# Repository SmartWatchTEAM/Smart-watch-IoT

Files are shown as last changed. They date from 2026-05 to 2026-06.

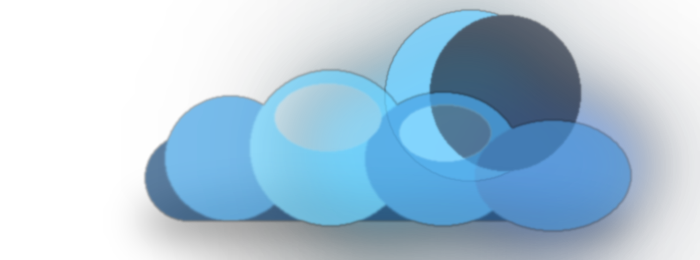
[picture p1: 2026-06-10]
Health_Tracking_Website/assets/images/cloud_weather_transparent.png

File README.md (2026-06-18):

# IoT-based Medical Alert System for Elderly People

## 1. Giới thiệu dự án

**IoT-based Medical Alert System for Elderly People** là đồ án xây dựng mô hình **đồng hồ giám sát sức khỏe thông minh cho người cao tuổi**. Hệ thống sử dụng **ESP32-S3 Super Mini** làm bộ xử lý trung tâm, kết hợp với cảm biến **MAX30102**, cảm biến chuyển động **MPU6500**, màn hình **TFT ST7789**, nút SOS, buzzer và nền tảng **Firebase Realtime Database** để theo dõi dữ liệu sức khỏe theo thời gian thực.

Thiết bị được thiết kế theo hướng nhỏ gọn, có thể hiển thị trực tiếp thông tin trên màn hình TFT và đồng thời gửi dữ liệu lên web dashboard để người thân theo dõi từ xa. Khi phát hiện tình huống bất thường như té ngã hoặc người dùng nhấn giữ nút SOS, hệ thống sẽ kích hoạt cảnh báo tại thiết bị và cập nhật trạng thái lên Firebase để hỗ trợ gửi thông báo cảnh báo.

> **Lưu ý:** Đây là mô hình phục vụ học tập, nghiên cứu và minh họa ứng dụng IoT trong chăm sóc sức khỏe. Kết quả đo BPM và SpO2 chỉ mang tính tham khảo, không thay thế thiết bị y tế chuyên dụng.

---

## 2. Thông tin

### Thành viên thực hiện

| Họ và tên | MSSV |
|---|---|
| Trần Hải Đạt | 24110197 |
| Nguyễn Lê Huy | 24110221 |
| Ninh Nguyễn Minh Tuyên | 24110372 |

---

## 3. Mục tiêu hệ thống

Mục tiêu của đề tài là xây dựng một mô hình đồng hồ sức khỏe IoT có khả năng hỗ trợ theo dõi một số thông số cơ bản của người cao tuổi và cảnh báo khi có tình huống nguy hiểm.

Các mục tiêu chính:

1. Đo nhịp tim BPM bằng cảm biến MAX30102.
2. Đo nồng độ oxy trong máu SpO2 bằng cảm biến MAX30102.
3. Đếm số bước chân bằng dữ liệu chuyển động từ MPU6500.
4. Phát hiện té ngã dựa trên gia tốc, góc nghiêng và trạng thái bất động.
5. Hiển thị thời gian, thời tiết, Wi-Fi, pin, BPM, SpO2 và số bước chân trên màn hình TFT ST7789.
6. Kích hoạt cảnh báo khi phát hiện té ngã hoặc khi người dùng nhấn giữ nút SOS.
7. Gửi dữ liệu sức khỏe và trạng thái cảnh báo lên Firebase Realtime Database.
8. Hiển thị dữ liệu realtime, lịch sử đo và thống kê trên web dashboard.
9. Hỗ trợ xuất báo cáo thống kê sức khỏe ra file PDF.

---

## 4. Chức năng chính

### 4.1. Đo nhịp tim và SpO2

Cảm biến **MAX30102** đọc tín hiệu ánh sáng đỏ và hồng ngoại từ người dùng. Sau khi thu thập đủ mẫu, chương trình xử lý tín hiệu để tính toán:

- Nhịp tim theo đơn vị **BPM**.
- Nồng độ oxy trong máu **SpO2**.
- Trạng thái đặt tay lên cảm biến.
- Chất lượng tín hiệu đo.

Khi tín hiệu chưa ổn định hoặc chưa đặt tay đúng vị trí, giao diện sẽ hiển thị giá trị dạng `--` để tránh hiển thị sai.

### 4.2. Đếm số bước chân

Cảm biến **MPU6500** cung cấp dữ liệu gia tốc theo ba trục. Chương trình phân tích dao động gia tốc để xác định bước đi, từ đó cập nhật:

- Tổng số bước trong ngày.
- Mục tiêu bước chân.
- Phần trăm hoàn thành mục tiêu.
- Quãng đường ước tính.
- Lượng calo ước tính.

### 4.3. Phát hiện té ngã

Hệ thống sử dụng MPU6500 để đo gia tốc, góc nghiêng và trạng thái chuyển động của thiết bị. Thuật toán phát hiện té ngã được xây dựng theo chuỗi trạng thái nhằm hạn chế báo động giả:

```text
Hoạt động bình thường
→ Nghi ngờ rơi tự do
→ Phát hiện va chạm mạnh
→ Kiểm tra góc nghiêng
→ Kiểm tra bất động sau va chạm
→ Xác nhận té ngã
```

Khi té ngã được xác nhận, thiết bị sẽ:

- Hiển thị trạng thái cảnh báo trên màn hình TFT.
- Bật buzzer cảnh báo tại chỗ.
- Cập nhật trạng thái `fall` lên Firebase.
- Cho phép dashboard hiển thị cảnh báo để người thân theo dõi.

### 4.4. Cảnh báo SOS

Nút SOS được dùng để người dùng chủ động gửi cảnh báo khẩn cấp. Để hạn chế bấm nhầm, chức năng SOS được thiết kế theo dạng **nhấn giữ**.

Khi SOS được kích hoạt, hệ thống sẽ:

- Hiển thị cảnh báo SOS trên màn hình.
- Phát âm thanh bằng buzzer.
- Gửi trạng thái SOS lên Firebase.
- Hỗ trợ hệ thống web/email thông báo cho người thân.

### 4.5. Hiển thị trên màn hình TFT

Màn hình **TFT ST7789 1.69 inch** hiển thị giao diện đồng hồ thông minh với các thông tin:

- Thời gian và ngày tháng.
- Trạng thái Wi-Fi.
- Dung lượng pin.
- Thời tiết hiện tại.
- Nhịp tim BPM.
- SpO2.
- Số bước chân.
- Trạng thái té ngã và SOS.

### 4.6. Web dashboard và Firebase

ESP32-S3 gửi dữ liệu lên **Firebase Realtime Database**. Web dashboard đọc dữ liệu từ Firebase và hiển thị trên trình duyệt máy tính hoặc điện thoại.

Dashboard hỗ trợ các nhóm chức năng:

| Tab | Chức năng |
|---|---|
| Tổng quát | Hiển thị realtime BPM, SpO2, bước chân, trạng thái cảnh báo |
| Thống kê | Lọc dữ liệu theo ngày/tháng, biểu đồ BPM và SpO2, xuất PDF |
| Thiết bị | Hiển thị trạng thái cảm biến, kết nối, Firebase latest/history |
| Cảnh báo | Theo dõi Fall Detection, SOS Alert và bất thường sức khỏe |
| Cài đặt | Cấu hình ngưỡng cảnh báo và thông tin hệ thống |

---

## 5. Linh kiện sử dụng

| STT | Linh kiện | Chức năng |
|---|---|---|
| 1 | ESP32-S3 Super Mini | Bộ xử lý trung tâm, xử lý dữ liệu cảm biến và kết nối Wi-Fi |
| 2 | MAX30102 | Đo nhịp tim và SpO2 |
| 3 | MPU6500 | Đo gia tốc, con quay hồi chuyển, đếm bước chân và phát hiện té ngã |
| 4 | TFT ST7789 1.69 inch | Hiển thị giao diện đồng hồ sức khỏe |
| 5 | Nút chức năng | Chuyển màn hình hoặc điều khiển một số chức năng thiết bị |
| 6 | Nút SOS | Kích hoạt cảnh báo khẩn cấp khi nhấn giữ |
| 7 | Buzzer | Phát cảnh báo âm thanh khi có té ngã hoặc SOS |
| 8 | Pin Li-Po 3.7V | Cấp nguồn cho thiết bị |
| 9 | TP4056 + DW01 | Sạc và bảo vệ pin Li-Po |
| 10 | Dây nối / nguồn cấp | Kết nối phần cứng và cấp nguồn thử nghiệm |

---

## 6. Sơ đồ khối hệ thống

```text
+-------------------+        I2C        +-------------------+
|    MAX30102       | ----------------> |                   |
|  BPM / SpO2       |                   |                   |
+-------------------+                   |                   |
                                        |                   |
+-------------------+        I2C        |     ESP32-S3      |       SPI       +------------------+
|     MPU6500       | ----------------> |    Super Mini     | --------------> |   TFT ST7789     |
| Steps / Fall      |                   |                   |                 |    Display       |
+-------------------+                   |                   |                 +------------------+
                                        |                   |
+-------------------+       GPIO        |                   |       GPIO      +------------------+
|  Nút chức năng    | ----------------> |                   | --------------> |      Buzzer      |
|  Nút SOS          |                   |                   |                 |   Cảnh báo       |
+-------------------+                   +---------+---------+                 +------------------+
                                                  |
                                                  | Wi-Fi / HTTPS
                                                  v
                                      +------------------------+
                                      | Firebase Realtime DB   |
                                      | latest / history /daily|
                                      +-----------+------------+
                                                  |
                                                  v
                                      +------------------------+
                                      | Web Dashboard          |
                                      | Realtime / Chart / PDF |
                                      +------------------------+
```

---

## 7. Sơ đồ kết nối phần cứng

> Bảng dưới đây được trình bày theo cấu hình phần cứng trong báo cáo đồ án. Nếu thay đổi chân GPIO trong firmware, cần cập nhật lại bảng này cho đồng bộ.

### 7.1. Cảm biến MAX30102

| MAX30102 | ESP32-S3 Super Mini |
|---|---|
| SDA | GPIO 10 |
| SCL | GPIO 11 |
| VCC | 3.3V |
| GND | GND |

### 7.2. Cảm biến MPU6500

| MPU6500 | ESP32-S3 Super Mini |
|---|---|
| SDA | GPIO 12 |
| SCL | GPIO 13 |
| VCC | 3.3V |
| GND | GND |

### 7.3. Màn hình TFT ST7789

| TFT ST7789 | ESP32-S3 Super Mini |
|---|---|
| SCLK | GPIO 2 |
| MOSI | GPIO 3 |
| CS | GPIO 6 |
| RST | GPIO 4 |
| DC | GPIO 5 |
| BL | GPIO 7 |
| VCC | 3.3V |
| GND | GND |

### 7.4. Nút nhấn

| Thiết bị | ESP32-S3 Super Mini |
|---|---|
| Nút chức năng | GPIO 9 |
| Nút SOS | GPIO 15 |

---

## 8. Kiến trúc dữ liệu Firebase

Hệ thống sử dụng **Firebase Realtime Database** để lưu dữ liệu realtime và dữ liệu lịch sử.

```text
devices/
└── watch_001/
    ├── latest/
    │   ├── bpm
    │   ├── spo2
    │   ├── steps
    │   ├── fall
    │   ├── sos
    │   ├── battery
    │   ├── wifi
    │   ├── timeText
    │   ├── dateText
    │   └── updatedAt
    │
    ├── history/
    │   └── YYYY-MM-DD/
    │       └── auto-id hoặc timestamp
    │           ├── bpm
    │           ├── spo2
    │           ├── steps
    │           ├── fall
    │           ├── sos
    │           └── createdAt
    │
    └── daily/
        └── YYYY-MM-DD/
            └── summary/
                ├── steps
                ├── stepGoal
                ├── distanceKm
                ├── calories
                └── updatedAt
```

Ý nghĩa các nhánh chính:

| Nhánh | Chức năng |
|---|---|
| `latest` | Lưu trạng thái mới nhất của thiết bị để dashboard hiển thị realtime |
| `history/YYYY-MM-DD` | Lưu lịch sử đo theo ngày để vẽ biểu đồ và thống kê |
| `daily/YYYY-MM-DD/summary` | Lưu tổng hợp dữ liệu vận động trong ngày |

---

## 9. Nguyên lý hoạt động

Khi thiết bị được cấp nguồn, ESP32-S3 tiến hành khởi tạo màn hình TFT, cảm biến MAX30102, cảm biến MPU6500, nút nhấn, buzzer và kết nối Wi-Fi.

Nếu Wi-Fi kết nối thành công, hệ thống đồng bộ thời gian NTP và lấy dữ liệu thời tiết từ Internet. Nếu Wi-Fi chưa kết nối, thiết bị vẫn có thể đo và hiển thị dữ liệu cục bộ trên màn hình.

Trong vòng lặp chính, hệ thống thực hiện các tác vụ:

1. Đọc trạng thái nút chức năng và nút SOS.
2. Đọc tín hiệu IR/Red từ MAX30102.
3. Kiểm tra người dùng đã đặt tay lên cảm biến hay chưa.
4. Thu thập đủ mẫu và tính BPM, SpO2.
5. Đọc dữ liệu gia tốc và góc nghiêng từ MPU6500.
6. Đếm bước chân và kiểm tra điều kiện té ngã.
7. Cập nhật giao diện TFT theo màn hình hiện tại.
8. Bật buzzer nếu có cảnh báo Fall hoặc SOS.
9. Gửi dữ liệu realtime và lịch sử lên Firebase khi Wi-Fi hoạt động.
10. Web dashboard đọc dữ liệu Firebase để hiển thị và xuất báo cáo.

---

## 10. Cấu trúc firmware ESP32

Firmware được chia thành nhiều file `.ino` để dễ quản lý theo từng chức năng:

| File | Vai trò |
|---|---|
| `SmartWatch.ino` | File chính, khai báo biến toàn cục, `setup()` và `loop()` |
| `01_Button.ino` | Xử lý nút chức năng, nút SOS và thao tác người dùng |
| `02_I2C.ino` | Khởi tạo và kiểm tra bus I2C |
| `03_WiFi_Time_Weather.ino` | Kết nối Wi-Fi, đồng bộ thời gian NTP và lấy dữ liệu thời tiết |
| `04_MAX30102.ino` | Đọc MAX30102, xử lý BPM và SpO2 |
| `05_MPU6500.ino` | Đọc MPU6500, tính gia tốc và góc nghiêng |
| `06_StepTracker.ino` | Đếm bước chân, tính quãng đường và calo |
| `07_UI_Common.ino` | Các hàm vẽ giao diện chung |
| `08_UI_Home.ino` | Giao diện màn hình chính |
| `09_UI_Health.ino` | Giao diện đo sức khỏe BPM và SpO2 |
| `10_UI_Steps.ino` | Giao diện bước chân |
| `11_Alert_Buzzer.ino` | Xử lý cảnh báo và buzzer |
| `12_Firebase.ino` | Gửi dữ liệu latest, history và daily summary lên Firebase |

---

## 11. Cấu trúc web dashboard

Web dashboard được xây dựng bằng **HTML, CSS và JavaScript**, kết nối trực tiếp với Firebase Realtime Database.

Cấu trúc thư mục đề xuất:

```text
web-dashboard/
├── index.html
├── css/
│   ├── base.css
│   ├── layout.css
│   ├── sidebar.css
│   ├── cards.css
│   ├── tabs.css
│   └── responsive.css
├── js/
│   ├── app.js
│   ├── config/
│   │   └── firebaseConfig.js
│   ├── core/
│   │   ├── header.js
│   │   ├── router.js
│   │   └── sidebar.js
│   ├── services/
│   │   ├── firebaseService.js
│   │   └── statsService.js
│   ├── tabs/
│   │   ├── overviewTab.js
│   │   ├── statsTab.js
│   │   ├── deviceTab.js
│   │   ├── alertsTab.js
│   │   └── settingsTab.js
│   └── utils/
│       └── format.js
└── assets/
    └── icons/
```

---

## 12. Cài đặt phần mềm

### 12.1. Phần mềm cần có

- Arduino IDE 2.x.
- ESP32 board package by Espressif Systems.
- Trình duyệt web hiện đại như Chrome, Edge hoặc Firefox.
- Firebase project có bật Realtime Database.
- Node.js hoặc Firebase CLI nếu cần deploy web dashboard.

### 12.2. Thư viện Arduino cần cài

Trong Arduino IDE, vào:

```text
Sketch > Include Library > Manage Libraries
```

Cài các thư viện:

| Thư viện | Chức năng |
|---|---|
| Adafruit GFX Library | Thư viện đồ họa cơ bản |
| Adafruit ST7735 and ST7789 Library | Điều khiển màn hình TFT ST7789 |
| SparkFun MAX3010x Pulse and Proximity Sensor Library | Đọc cảm biến MAX30102 |
| Wire | Giao tiếp I2C |
| WiFi | Kết nối Wi-Fi ESP32 |
| HTTPClient | Gửi request HTTP/HTTPS |

### 12.3. Cài ESP32 board package

Trong Arduino IDE:

```text
File > Preferences
```

Thêm URL sau vào `Additional Boards Manager URLs`:

```text
https://espressif.github.io/arduino-esp32/package_esp32_index.json
```

Sau đó vào:

```text
Tools > Board > Boards Manager
```

Tìm và cài:

```text
esp32 by Espressif Systems
```

---

## 13. Cách chạy firmware

### Bước 1: Mở project firmware

Mở file chính:

```text
SmartWatch.ino
```

Arduino IDE sẽ tự mở các file `.ino` còn lại trong cùng thư mục.

### Bước 2: Chọn board

```text
Tools > Board > ESP32S3 Dev Module
```

### Bước 3: Chọn cổng COM

```text
Tools > Port > COMx
```

### Bước 4: Cấu hình Wi-Fi và Firebase

Trong firmware, cập nhật các thông tin:

```cpp
const char* WIFI_SSID = "TEN_WIFI";
const char* WIFI_PASSWORD = "MAT_KHAU_WIFI";
```

Cấu hình Firebase theo project của nhóm:

```text
Firebase Realtime Database URL
Firebase Auth / Secret hoặc cấu hình xác thực tương ứng
Device ID: watch_001
```

### Bước 5: Nạp chương trình

Bấm `Verify`, sau đó bấm `Upload`.

Nếu upload bị dừng ở `Connecting...`, giữ nút `BOOT` trên ESP32-S3 trong lúc upload, sau đó thả ra khi quá trình nạp bắt đầu.

### Bước 6: Kiểm tra Serial Monitor

Mở Serial Monitor ở baudrate:

```text
115200
```

Kết quả mong đợi:

```text
MAX30102 SUCCESS
MPU6500 SUCCESS
WiFi SUCCESS
Firebase telemetry OK
```

---

## 14. Cách chạy web dashboard

### 14.1. Chạy bằng Live Server

Mở thư mục web dashboard trong VS Code, sau đó mở file:

```text
index.html
```

Chọn:

```text
Open with Live Server
```

### 14.2. Deploy bằng Firebase Hosting

Cài Firebase CLI:

```bash
npm install -g firebase-tools
```

Đăng nhập Firebase:

```bash
firebase login
```

Khởi tạo hosting nếu chưa có:

```bash
firebase init hosting
```

Deploy:

```bash
firebase deploy
```

Sau khi deploy, có thể truy cập dashboard bằng link Firebase Hosting của project.

---

## 15. Kiểm thử hệ thống

### 15.1. Kiểm thử MAX30102

| Trường hợp | Kết quả mong đợi |
|---|---|
| Chưa đặt tay lên cảm biến | Hiển thị `BPM: --`, `SpO2: --` |
| Đặt tay đúng vị trí và giữ yên | Sau khi đủ mẫu, hiển thị BPM và SpO2 |
| Tay rung hoặc đặt lệch | Có thể hiển thị `--` hoặc báo tín hiệu chưa ổn định |
| Nhấc tay ra khỏi cảm biến | Hệ thống dừng đo và chờ đặt tay lại |

### 15.2. Kiểm thử MPU6500

| Trường hợp | Kết quả mong đợi |
|---|---|
| Thiết bị đứng yên | Không báo té ngã |
| Di chuyển nhẹ | Không báo té ngã, có thể đếm bước |
| Mô phỏng rơi/va chạm/nghiêng mạnh | Có thể kích hoạt kiểm tra té ngã |
| Sau va chạm thiết bị nằm yên | Xác nhận `Fall Alert` nếu thỏa điều kiện |

### 15.3. Kiểm thử SOS và buzzer

| Trường hợp | Kết quả mong đợi |
|---|---|
| Nhấn giữ nút SOS | Kích hoạt SOS Alert |
| Có Fall hoặc SOS | Buzzer phát cảnh báo |
| Tắt cảnh báo theo thao tác nút | Buzzer dừng cảnh báo |

### 15.4. Kiểm thử Firebase và dashboard

| Trường hợp | Kết quả mong đợi |
|---|---|
| ESP32 có Wi-Fi | Dữ liệu cập nhật vào `latest` |
| Đo xong BPM/SpO2 hợp lệ | Lưu bản ghi vào `history/YYYY-MM-DD` |
| Có Fall/SOS | Dashboard hiển thị cảnh báo |
| Chọn ngày/tháng trong tab Thống kê | Biểu đồ và bảng lịch sử được hiển thị |
| Bấm xuất PDF | Tạo báo cáo thống kê sức khỏe |

---

## 16. Kết quả đạt được

Hệ thống đã đạt được các chức năng chính của đề tài:

- Đọc và xử lý tín hiệu từ cảm biến MAX30102.
- Hiển thị nhịp tim BPM và SpO2 trên màn hình TFT.
- Đọc dữ liệu MPU6500 để tính chuyển động, số bước chân và hỗ trợ phát hiện té ngã.
- Xây dựng giao diện đồng hồ sức khỏe gồm Home, Health và Steps.
- Kết nối Wi-Fi để đồng bộ thời gian và lấy dữ liệu thời tiết.
- Gửi dữ liệu sức khỏe và trạng thái thiết bị lên Firebase.
- Xây dựng web dashboard theo dõi realtime, lịch sử đo và cảnh báo.
- Hỗ trợ xuất báo cáo thống kê sức khỏe ra PDF.

---

## 17. Khó khăn và cách khắc phục

| Khó khăn | Cách khắc phục |
|---|---|
| Chọn sai board trong Arduino IDE | Cài ESP32 board package và chọn đúng ESP32S3 Dev Module |
| Thiếu thư viện TFT hoặc MAX30102 | Cài thư viện trong Library Manager |
| MAX30102 dễ bị nhiễu | Điều chỉnh LED, giữ tay ổn định, kiểm tra IR/Red và lọc tín hiệu |
| Té ngã dễ báo sai nếu chỉ dùng một ngưỡng | Xây dựng thuật toán nhiều trạng thái gồm rơi tự do, va chạm, góc nghiêng và bất động |
| Wi-Fi không ổn định | Cho thiết bị chạy cục bộ khi mất mạng và reconnect khi cần gửi Firebase |
| Dữ liệu lịch sử chưa đủ | Chỉ lưu history khi có dữ liệu đo hợp lệ và duy trì gửi định kỳ |

---

## 18. Hạn chế

- Kết quả BPM và SpO2 chỉ mang tính tham khảo, chưa đạt chuẩn thiết bị y tế.
- Cảm biến MAX30102 nhạy với vị trí đặt tay, ánh sáng bên ngoài và chuyển động.
- Thuật toán phát hiện té ngã cần tiếp tục hiệu chỉnh khi thay đổi vị trí đeo thực tế.
- Mô hình chưa có vỏ đồng hồ hoàn chỉnh và chưa tối ưu hoàn toàn về năng lượng.
- Chưa tích hợp GPS thực tế để gửi vị trí khi có cảnh báo.

---

## 19. Hướng phát triển

Trong các phiên bản tiếp theo, hệ thống có thể được mở rộng:

1. Thiết kế vỏ đồng hồ và dây đeo hoàn chỉnh.
2. Tối ưu thuật toán lọc nhiễu MAX30102 để tăng độ ổn định BPM/SpO2.
3. Bổ sung GPS để gửi vị trí khi có Fall Alert hoặc SOS.
4. Tối ưu tiêu thụ năng lượng để kéo dài thời lượng pin.
5. Tích hợp Firebase Cloud Messaging hoặc ứng dụng mobile để gửi push notification.
6. Thêm eSIM hoặc kết nối dữ liệu di động để hoạt động khi không có Wi-Fi.
7. Thử nghiệm với nhiều người dùng hơn để đánh giá độ ổn định.
8. Thiết kế PCB riêng cho mô hình thiết bị đeo.
9. Bổ sung cảm biến nhiệt độ hoặc cảm biến huyết áp nếu điều kiện cho phép.

---

## 20. Lưu ý an toàn về nguồn pin

Module **TP4056 + DW01** có chức năng sạc và bảo vệ pin Li-Po 1 cell. Khi sử dụng cần lưu ý:

- Không đấu ngược cực pin.
- Không sạc khi pin hoặc module nóng bất thường.
- Không để pin bị chập mạch.
- Cần kiểm tra mức điện áp phù hợp trước khi cấp cho ESP32-S3 và các cảm biến.
- Với sản phẩm thực tế, nên sử dụng mạch quản lý nguồn chuyên dụng và vỏ bảo vệ an toàn.

---

## 21. Tài liệu tham khảo chính

Một số nhóm tài liệu được sử dụng trong quá trình thực hiện:

- Tài liệu về Internet of Things và kiến trúc hệ thống IoT.
- Tài liệu ESP32-S3 và lập trình Arduino IDE.
- Datasheet MAX30102.
- Tài liệu MPU6500.
- Tài liệu màn hình TFT ST7789 và thư viện Adafruit.
- Tài liệu Firebase Realtime Database.
- Tài liệu về phát hiện té ngã và chăm sóc sức khỏe người cao tuổi.

---

## 22. License

Dự án được phát triển cho mục đích học tập và nghiên cứu. Người dùng có thể tham khảo, chỉnh sửa và mở rộng với điều kiện ghi rõ nguồn khi chia sẻ lại.

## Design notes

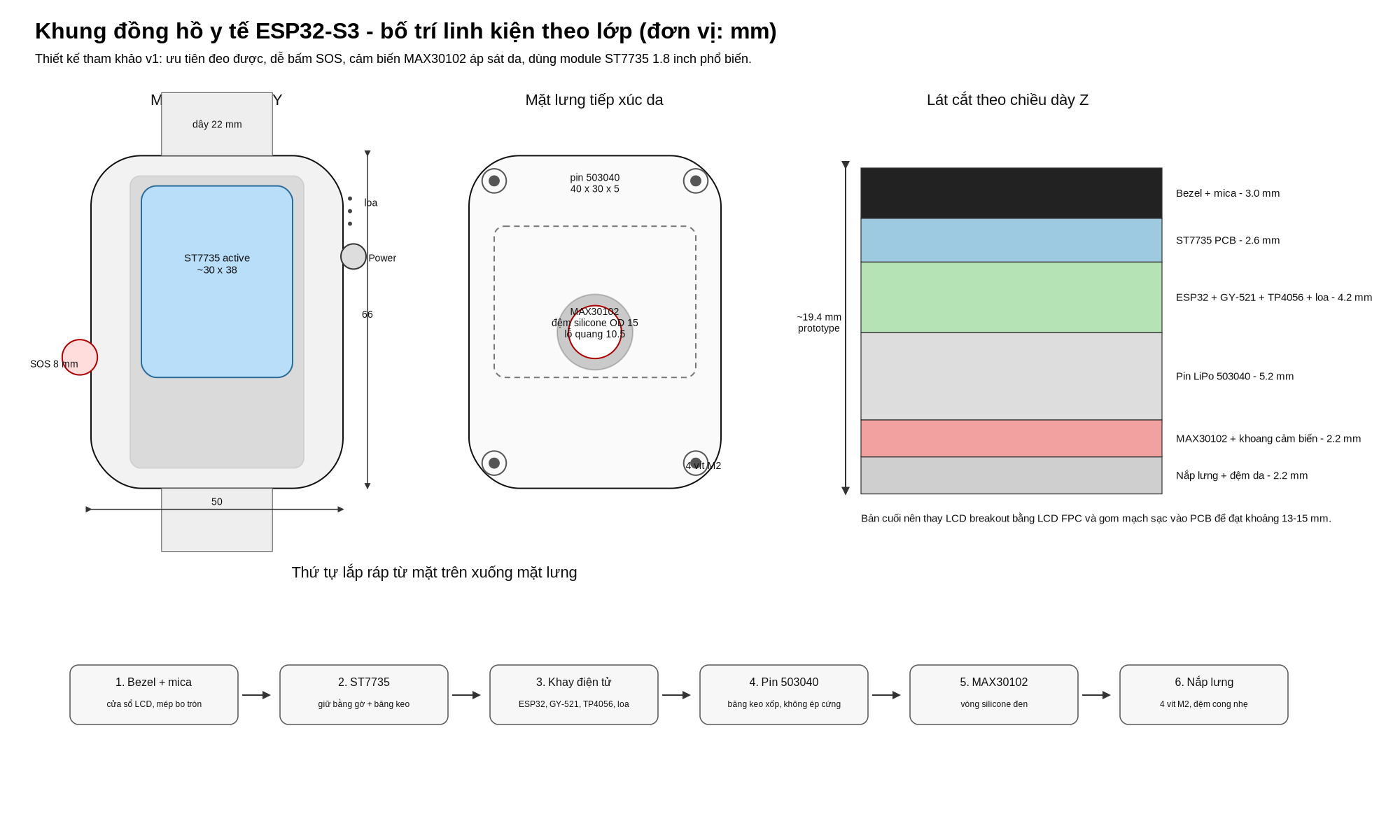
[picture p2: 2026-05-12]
senior_health_watch_layouts.png

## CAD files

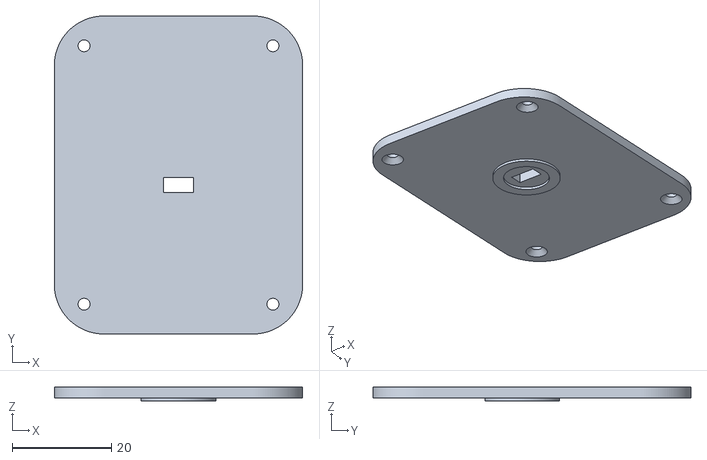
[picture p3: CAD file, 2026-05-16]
3D parts/Bottom.stl
50.0 x 64.0 x 2.80

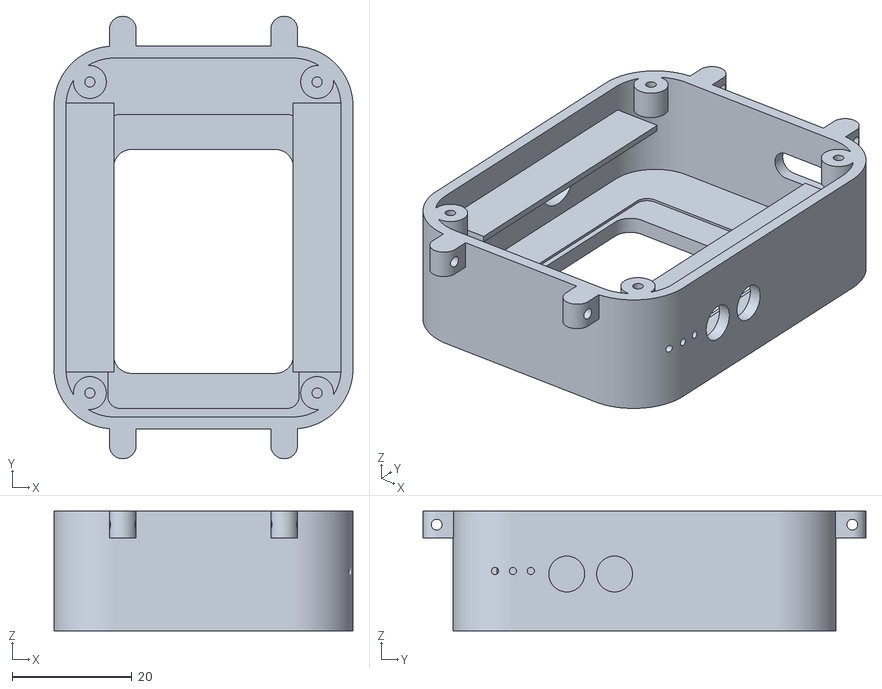
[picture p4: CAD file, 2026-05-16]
3D parts/Top.stl
50.0 x 74.0 x 20.0

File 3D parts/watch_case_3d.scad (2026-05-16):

// senior_health_watch_case_v1.scad
// Parametric prototype case for ESP32-S3 Super Mini + ST7735 + MAX30102 + GY-521 + TP4056 + 503040 LiPo
// Units: mm. Open with OpenSCAD. Set VIEW to: "assembly", "shell", "bezel", "backplate", "components".
    
$fn = 128;
VIEW = "backplate";
SHOW_COMPONENTS = true;

// ==== Main dimensions ====
case_w = 50;    
case_h = 64;     
case_z = 20;    
corner_r = 10;
wall = 2.0;
bezel_z = 3.0;
back_z = 2.2;
tray_z = 1.6;
strap_w = 22;
strap_lug_gap = 22.5;
lug_w = 4.5; 
lug_h = 6.5;
lug_z = 4.5; 

// ==== DISPLAY MODULE ====

// PCB tổng của module màn hình
// [width, height, thickness]
display_pcb = [31.38, 48.56, 3.0];

// Kính LCD / toàn bộ phần panel hiển thị
// dùng để kiểm tra va chạm cơ khí
lcd_panel = [30.07, 37.43, 2.2];

// Viewing Area (VA)
// vùng nhìn thấy khi màn sáng
// đây là kích thước nên dùng cho cửa sổ bezel
VA_lcd = [29.37, 34.33, 0.8];

// Active Area (AA)
// vùng pixel thật
// thường không dùng trực tiếp để cắt bezel
AA_lcd = [27.97, 32.63, 0.8];

// ==== MAIN BOARDS ====

// ESP32-S3 Super Mini
esp32_s3    = [25, 18.2, 4.5];

// GY-521 MPU6050
gy521       = [21.8, 17.0, 3.0];

// TP4056 USB-C charging board
tp4056      = [25.0, 19.0, 4.0];

// pin lipo
battery     = [54.0, 34.0, 4.0];     // 403450 

// cảm biến nhịp tim
max30102mod = [20.3, 15.5, 3.5];     

// mini speaker
speaker     = [12.0, 12.0, 3.0];

module rr2d(w,h,r){
    offset(r=r) offset(delta=-r) square([w,h], center=true);
}
module rounded_box(w,h,z,r){
    linear_extrude(height=z) rr2d(w,h,r);
}
module screw_hole(x,y,z=30){
    translate([x,y,-1]) cylinder(h=z, d=2.25);
}

module screw_boss_bottom(x, y, zpos, h=4.5, od=5.5, pilot_d=1.7) {
    translate([x, y, zpos])
        difference() {
            cylinder(h = h, d = od);
            translate([0, 0, -1])
                cylinder(h = h + 2, d = pilot_d);
        }
}
module strap_lugs(zbase=0){
    for(dir=[1, -1]) {
        // Xác định tâm của ngàm (và cũng là tâm của lỗ xỏ chốt)
        y_center = dir * (case_h/2 + lug_h/2 - 0.5);
        
        for(x=[-(strap_lug_gap/2+lug_w/2), (strap_lug_gap/2+lug_w/2)]){
            
            difference() {
                // Dùng lệnh hull() bọc 1 hình trụ ở ngoài và 1 mặt phẳng bám vào thân vỏ 
                // để tạo ra dáng ngàm chữ D (D-shape) bo tròn hoàn toàn
                hull() {
                    // Phần đuôi ngàm là hình trụ tròn (tâm trùng với chốt)
                    translate([x, y_center, zbase + lug_z/2]) 
                        cylinder(h=lug_z, d=lug_w, center=true);
                    
                    // Phần gốc ngàm bám sát vào mặt vỏ đồng hồ
                    translate([x, y_center - dir * (lug_h/2 - 0.5), zbase + lug_z/2]) 
                        cube([lug_w, 0.1, lug_z], center=true);
                }
                
                // Đục lỗ xỏ chốt dây đeo lò xo (đường kính 1.8mm chống kẹt)
                translate([x, y_center, zbase + lug_z/2]) 
                    rotate([0,90,0]) 
                        cylinder(h=lug_w+2, d=1.8, center=true);
            }
            
        }
    }
}

module shell_body() {
    difference() {
        union() {
            // Khối vỏ ngoài bây giờ cao lên tận đỉnh màn hình (case_z = 20)
            rounded_box(case_w, case_h, case_z, corner_r);
            strap_lugs(0);
        }

        // 1. Khoang rỗng bên trong (đục từ dưới bụng lên, chừa lại cái "nóc" dày 3mm)
        translate([0, 0, -0.1])
            rounded_box(
                case_w - 2 * wall,
                case_h - 2 * wall,
                case_z - bezel_z + 0.1,
                corner_r - wall
            );

        // 2. Cửa sổ màn hình (khoét xuyên qua lớp nóc trên cùng)
        translate([0, 4, case_z - bezel_z - 0.2])
            rounded_box(lcd_panel[0], lcd_panel[1], bezel_z + 1, 3.0);

        // 3. Hốc chứa ngàm PCB màn hình (nằm kề ngay dưới cửa sổ)
        translate([0, 4, case_z - bezel_z - 1.8])
            rounded_box(display_pcb[0] + 0.6, display_pcb[1] + 0.6, 2.2, 2.0);

        // 4. Cổng sạc Type-C (Đã dịch phải X = 8.5 khớp với Tray)
        translate([8.5, -case_h / 2 - 0.1, 8.2]) {
            rotate([90, 0, 0]) {
                hull() {
                    translate([-3.25, 0, 0]) cylinder(h = 5.0, d = 4.5, center = true);
                    translate([3.25, 0, 0]) cylinder(h = 5.0, d = 4.5, center = true);
                }
            }
        }

        // 5. Nút nguồn bên phải
        translate([case_w / 2 + 0.05, 5, 10.5])
            rotate([0, 90, 0]) cylinder(h = 5, d = 6.0, center = true);
        
        translate([case_w / 2 + 0.05, 13, 10.5])
            rotate([0, 90, 0]) cylinder(h = 5, d = 6.0, center = true);

        // 6. Nút SOS bên trái
        translate([-case_w / 2 - 0.05, -7, 10.5])
            rotate([0, 90, 0]) cylinder(h = 5, d = 8.5, center = true);

        // 7. Lỗ loa ở cạnh phải phía trên
        for (i = [-1, 0, 1])
            translate([case_w / 2 + 0.05, 22 + i * 3, 10.0])
                rotate([0, 90, 0]) cylinder(h = 5, d = 1.2, center = true);
    }

    // CHỈ GIỮ LẠI: screw boss phía dưới cho nắp lưng backplate
    // (Đã dọn dẹp sạch sẽ phần cọc vít đỉnh vì vỏ đã liền khối)
    for (x = [-(case_w / 2 - 6), (case_w / 2 - 6)])
        for (y = [-(case_h / 2 - 6), (case_h / 2 - 6)])
            screw_boss_bottom(x, y, 0);

    // Gân giữ pin
    translate([-19.5, 0, 5.0]) 
        cube([9, 45, 1.0], center = true); // Thanh ray bên trái
        
    translate([19.5, 0, 5.0]) 
        cube([9, 45, 1.0], center = true); // Thanh ray bên phải
}


module backplate() {
    difference() {
        translate([0, 0, -back_z])
            rounded_box(case_w, case_h, back_z, corner_r);

        // 1. Cửa sổ cảm biến MAX30102 (Lỗ hình chữ nhật 6x3 mm)
        translate([0, -2, -back_z - 0.5])
            linear_extrude(height = back_z + 1.5)
                square([6.0, 3.0], center = true);

        // lỗ vít nắp lưng
        for (x = [-(case_w / 2 - 6), (case_w / 2 - 6)])
            for (y = [-(case_h / 2 - 6), (case_h / 2 - 6)]){
                // lỗ xuyên vít M2
                translate([x, y, -back_z - 1])
                    cylinder(h = back_z + 4, d = 2.4);

                // countersink cho đầu vít
                translate([x, y, -back_z - 0.01])
                    cylinder(h = 1.2, d1 = 4.8, d2 = 2.4);
            }
    }

    // đệm cảm biến
    translate([0, -2, -back_z - 0.6])
        difference() {
            cylinder(h = 0.8, d = 15.0);
            translate([0, 0, -0.1]) cylinder(h = 1.1, d = 10.2);
        }
}

module comp_box(size, loc, col=[0.3,0.3,0.3,0.45]){
    color(col) translate(loc) cube(size, center=true);
}
module components() {
    // màn hình: đúng các lớp bạn khai báo
    comp_box(display_pcb, [0, 4, case_z - 4.6], [0.05, 0.05, 0.05, 0.40]);
    comp_box(lcd_panel,   [0, 4, case_z - 3.0], [0.10, 0.40, 0.90, 0.65]);
    comp_box(VA_lcd,      [0, 4, case_z - 3.0], [0.10, 0.80, 0.90, 0.35]);
    comp_box(AA_lcd,      [0, 4, case_z - 3.0], [0.10, 0.95, 0.30, 0.25]);

    // các board khác
    comp_box(esp32_s3,    [-11, 10, 9.7], [0.00, 0.45, 0.80, 0.55]);
    comp_box(gy521,       [-11, -16, 9.7], [0.85, 0.55, 0.05, 0.55]);
    comp_box(tp4056,      [8, -18, 9.6], [0.10, 0.75, 0.20, 0.55]);
    comp_box(speaker,     [14, 21, 9.6], [0.85, 0.15, 0.15, 0.60]);

    // pin LiPo: giữ nguyên kích thước đã khai báo, chỉ xoay để vừa case 44 x 60
    color([0.55, 0.55, 0.55, 0.50])
        translate([0, 0, 4.0])
            rotate([0, 0, 90])
                cube(battery, center = true);

    comp_box(max30102mod, [0, -2, 0.8], [0.65, 0.05, 0.05, 0.60]);
}


if (VIEW == "shell") {
    // Tự động lật úp bề mặt màn hình xuống bàn in Z=0 để bề mặt trơn láng nhất
    translate([0, 0, case_z])
        rotate([180, 0, 0])
            shell_body();
} 
else if (VIEW == "backplate") {
    // Nâng backplate lên mặt phẳng in (Z=0)
    translate([0, 0, back_z]) 
        backplate();
} 

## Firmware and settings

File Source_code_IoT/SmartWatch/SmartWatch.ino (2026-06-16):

#include <Arduino.h>
#include <Wire.h>
#include <SPI.h>
#include <math.h>
#include <stdlib.h>
#include <WiFi.h>
#include <time.h>
#include <HTTPClient.h>
#include <WiFiClientSecure.h>
#include <Preferences.h>

#include <Adafruit_GFX.h>
#include <Adafruit_ST7789.h>

#include "MAX30105.h"
#include "spo2_algorithm.h"

#include <Fonts/FreeSans9pt7b.h>
#include <Fonts/FreeSansBold9pt7b.h>
#include <Fonts/FreeSansBold18pt7b.h>
#include <Fonts/FreeSansBold24pt7b.h>

// =======================================================
// PIN CONFIG - ESP32-S3 SUPER MINI
// =======================================================

// I2C bus 0 cho MPU6050
#define MPU_SDA 12
#define MPU_SCL 13

// I2C bus 1 cho MAX30102
#define MAX_SDA 10
#define MAX_SCL 11

// SOS

// TFT ST7789V3 SPI
#define TFT_WIDTH   240
#define TFT_HEIGHT  280

#define TFT_SCLK 2
#define TFT_MOSI 3
#define TFT_CS   6
#define TFT_RST  4
#define TFT_DC   5
#define TFT_BL   7

// Buzzer
#define BUZZER_PIN 14

// Nút bấm chức năng
// Nút A: nhấn ngắn chuyển sang màn hình kế tiếp: Home -> Health -> Steps -> Home.
// Nút B: nhấn ngắn chuyển về màn hình trước đó: Home -> Steps -> Health -> Home.
// Nhấn giữ A hoặc B >= 2 giây: kích hoạt SOS.
// Đấu nút: 1 chân vào GPIO, 1 chân vào GND vì code dùng INPUT_PULLUP.
#define BTN_A_PIN 8
#define BTN_B_PIN 9

// Mac dinh khong do dien ap pin vi mach hien tai chi cap nguon:
// BAT- -> GND, BAT+ -> cong tac -> 5V ESP32.
// Khong co day ADC/cau chia ap thi chi uoc luong % theo thoi gian dung.
#define BATTERY_USE_ADC 0
#define BAT_ADC_PIN 1

// Địa chỉ I2C
#define MAX30102_ADDR 0x57

// =======================================================
// TFT
// =======================================================

Adafruit_ST7789 tft = Adafruit_ST7789(TFT_CS, TFT_DC, TFT_RST);

bool uiDrawn = false;

// =======================================================
// UI COLORS
// =======================================================
#define COLOR_BG          ST77XX_BLACK
#define COLOR_PANEL       0x1082
#define COLOR_CARD_BLUE   0x0254
#define COLOR_CARD_RED    0x2800
#define COLOR_CARD_GREEN  0x0200
#define COLOR_BORDER      0x8410
#define COLOR_DIM         0x4208
#define COLOR_ACCENT      ST77XX_CYAN
#define COLOR_SUN         0xFD20
#define COLOR_SUN_CORE    ST77XX_YELLOW
#define COLOR_CLOUD       ST77XX_WHITE
#define COLOR_CLOUD_SHA   0xC618



// =======================================================
// WIFI / REAL TIME CLOCK - NTP
// =======================================================

const char* WIFI_SSID = "Redmi Note 11";
const char* WIFI_PASSWORD = "sos1676cc";

const long GMT_OFFSET_SEC = 7 * 3600;      // Viet Nam GMT+7
const int DAYLIGHT_OFFSET_SEC = 0;

unsigned long lastClockUpdate = 0;
const unsigned long CLOCK_UPDATE_INTERVAL = 1000;
bool timeSynced = false;

// =======================================================
// REAL WEATHER - OPEN-METEO
// =======================================================
// Tọa độ TP.HCM. Có thể đổi theo vị trí bạn muốn hiển thị thời tiết.
const float WEATHER_LAT = 10.8231;
const float WEATHER_LON = 106.6297;

unsigned long lastWeatherUpdate = 0;
const unsigned long WEATHER_UPDATE_INTERVAL = 10UL * 60UL * 1000UL; // cập nhật mỗi 10 phút

bool weatherReady = false;
String weatherTempText = "--";
String weatherDescText = "Offline";
String weatherHumidityText = "--";
String weatherWindText = "--";

// =======================================================
// WATCH FACE / MINI OS
// =======================================================

enum ScreenPage {
  SCREEN_HOME,
  SCREEN_HEALTH,
  SCREEN_STEPS
};

ScreenPage currentScreen = SCREEN_HOME;

// Dữ liệu giao diện chính. Giờ/ngày sẽ lấy từ NTP sau khi kết nối WiFi.
String currentTimeText = "--:--";
String currentDateText = "--, --/--";
String weatherCity = "TP.HCM";
String weatherText = "--C";
String spo2HomeText = "--";
int batteryPercent = 0;
float batteryVoltage = 0.0f;
float batteryFilteredVoltage = 0.0f;
unsigned long lastBatteryUpdate = 0;
unsigned long lastBatteryPersist = 0;
float batteryRuntimePercent = 100.0f;
Preferences batteryPrefs;
int quickBPM = 0;
bool wifiConnected = false;

unsigned long lastClockDemoUpdate = 0;
int demoHour = 14;
int demoMinute = 35;

// =======================================================
// MAX30102 / MAX30105 - THUAT TOAN DO CO TAY
// =======================================================

MAX30105 particleSensor;

// Che do do CO TAY: giu 500 mau @25Hz = khoang 20 giay.
// Co tay co song PPG yeu hon dau ngon tay, nen can cua so du dai + loc chuyen dong.
// Sau khi du 500 mau, moi lan them 200 mau moi se tinh lai tren cua so truot 20 giay.
// Nghia la giu 300 mau cu + nap 200 mau moi, cap nhat nhanh hon so voi do lai tu dau.
const int MAX_SAMPLE_RATE_HZ = 25;
const int SAMPLE_PERIOD_MS = 1000 / MAX_SAMPLE_RATE_HZ;              // 40ms/mau @25Hz
const int HR_MEASURE_SECONDS = 20;
const int BUFFER_LENGTH = 500;                                      // 500 mau = 20 giay @25Hz
const int NEW_SAMPLES = 200;                                      // cua so truot: giu 300 mau cu + nap 200 mau moi
const int SPO2_WINDOW_LENGTH = 100;                                 // thu vien Maxim chay an toan voi 100 mau
const int SPO2_WINDOW_COUNT = BUFFER_LENGTH / SPO2_WINDOW_LENGTH;    // 5 cua so SpO2 trong 20s
const int MAX_DETECTED_POINTS = 120;                                // du cho HR toi 160 BPM trong 20s

uint32_t irBuffer[BUFFER_LENGTH];
uint32_t redBuffer[BUFFER_LENGTH];
uint32_t sampleTimeBuffer[BUFFER_LENGTH];  // thoi diem tung mau, dung de tinh BPM dung khi toc do doc khong dung 25Hz

// Buffer phu dat global de tranh tran stack va tiet kiem RAM stack.
uint32_t irSortedBuffer[BUFFER_LENGTH];
uint32_t redSortedBuffer[BUFFER_LENGTH];
int32_t irACBuffer[BUFFER_LENGTH];
int32_t acAbsSortedBuffer[BUFFER_LENGTH];

int bufferIndex = 0;

int32_t spo2 = 0;
int8_t validSPO2 = 0;

int32_t heartRate = 0;
int8_t validHeartRate = 0;

// Gia tri da loc de hien thi len UI
int32_t displayHeartRate = 0;
int32_t displaySpO2 = 0;

bool fingerDetected = false;
bool maxReady = false;
bool mpuReady = false;

// Che do co tay: can tiep xuc ap sat hon dau ngon tay.
// Log cua ban: khong tiep xuc co luc IR ~16k-30k, tiep xuc tot ~82k-90k.
const uint32_t NO_FINGER_THRESHOLD = 35000;
const uint32_t FINGER_THRESHOLD    = 55000;
const uint32_t TARGET_IR_LOW       = 80000;   // vung muc tieu cho co tay
const uint32_t TARGET_IR_HIGH      = 145000;  // tranh bao hoa va tranh tang LED qua cao
const uint32_t SATURATION_LEVEL    = 245000;  // gan tran 262143 la bao hoa ADC

// LED co tay can manh hon dau ngon tay mot chut, nhung se bi khoa khi dang nap buffer.
byte maxLedLevel = 0x3C;
unsigned long lastLedAdjust = 0;
unsigned long lastHealthPrint = 0;
unsigned long ignoreSamplesUntil = 0;
unsigned long lastBufferProgressPrint = 0;

// Watchdog MAX30102: tự wake/reset khi mất LED, mất FIFO hoặc mất I2C.
unsigned long lastMaxSampleTime = 0;
unsigned long lastMaxWatchdogCheck = 0;
unsigned long lastMaxResetAttempt = 0;
uint8_t maxI2CFailCount = 0;
uint16_t maxZeroSampleCount = 0;

const unsigned long MAX_WATCHDOG_INTERVAL = 1000;  // kiểm tra MAX mỗi 1 giây
const unsigned long MAX_NO_SAMPLE_TIMEOUT = 15000; // tránh reset nhầm khi WiFi/Firebase làm loop bị chậm
const unsigned long MAX_RESET_COOLDOWN    = 10000; // tránh reset liên tục

const unsigned long FINGER_STABILIZE_MS = 3000; // co tay can 2-3 giay de ap luc/anh sang on dinh
const unsigned long LED_SETTLE_MS       = 1200; // bo qua mau sau khi doi LED lau hon vi co tay de bi troi DC

const byte HR_SMOOTH_SIZE = 9;
int hrHistory[HR_SMOOTH_SIZE];
byte hrHistoryCount = 0;
byte hrHistoryIndex = 0;
// Khong ep HR ve 70-100. Khoang nay de loc gia tri phi ly, van chap nhan HR cao/thap that neu song PPG du tot.
const int HR_ALGO_MIN_BPM = 40;
const int HR_ALGO_MAX_BPM = 135;

// Vung hien thi on dinh cho nguoi binh thuong luc nghi.
// Code KHONG ep gia tri gia; no uu tien/giu on dinh trong vung nay khi tin hieu PPG du tot.
// Neu BPM cao that va lap lai nhieu cua so voi chat luong cao, code van cho hien thi de canh bao.
const int HR_STABLE_LOW_BPM   = 71;
const int HR_STABLE_HIGH_BPM  = 90;
const int HR_HIGH_CONFIRM_BPM = 100;
const int HR_DANGER_BPM       = 120;
const int HR_ALERT_HIGH_BPM   = 110;
const int HR_ALERT_LOW_BPM    = 50;

const int SPO2_STABLE_LOW     = 95;
const int SPO2_STABLE_HIGH    = 100;
const int SPO2_LOW_CONFIRM    = 94;

const int HR_START_LOCK_COUNT = 1;
int hrPendingValue = 0;
byte hrPendingCount = 0;
int lastHRAuto = 0;
int lastHRExtrema = 0;
int lastHRCandidate = 0;
int lastHRWindowMedian = 0;
int lastHRWindowValidCount = 0;
float lastHRActualFs = 0;
uint32_t lastHRDurationMs = 0;
int lastHRAcRange = 0;
int lastHRThreshold = 0;
int lastHRPeakCount = 0;
int lastHRValleyCount = 0;
float lastHRAutoScore = 0;
int lastHRSpectrum = 0;
float lastHRSpectrumScore = 0;
float lastHRSpectrumSeparation = 0;
unsigned long lastLiveSpO2EstimateMs = 0;
int lastLiveSpO2Estimate = 0;
int lastLiveSpO2Quality = 0;
int lastRawRatioX100 = 0;
int lastAdjustedRatioX100 = 0;
int lastHRQuality = 0;
int lastHRRejectReason = 0;
float lastWristMotionScore = 0;
uint8_t wristBadSampleCount = 0;
uint16_t wristDroppedSamples = 0;
uint32_t lastGoodIRValue = 0;
uint32_t lastGoodREDValue = 0;

// Chong reset buffer qua nhay khi do co tay.
// 60 mau ~= 2.4 giay @25Hz, tranh reset buffer qua som khi day deo/co tay dao dong nhe.
const uint8_t WRIST_BAD_SAMPLE_RESET_COUNT = 60;

// Khi mat tiep xuc ngan/doi LED, chi giu ket qua cu vai giay roi an khoi man hinh/web.
unsigned long lastValidHeartRateMs = 0;
unsigned long lastValidSpO2Ms = 0;
unsigned long lastFingerLostMs = 0;
const unsigned long KEEP_LAST_HEALTH_VALUE_MS = 5000;

const byte SPO2_SMOOTH_SIZE = 5;
int spo2History[SPO2_SMOOTH_SIZE];
byte spo2HistoryCount = 0;
byte spo2HistoryIndex = 0;

struct SignalStats {
  uint32_t irMin;
  uint32_t irMax;
  uint32_t redMin;
  uint32_t redMax;
  uint32_t irAvg;
  uint32_t redAvg;
  uint32_t irAC;
  uint32_t redAC;
  float irACPercent;
  float redACPercent;
  uint8_t saturatedSamples;
};

SignalStats lastSignalStats;
bool signalOK = false;

// =======================================================
// MPU6500 - FALL DETECTION
// =======================================================

// Chip của bạn trả WHO_AM_I = 0x70, nên không dùng Adafruit_MPU6050.
// Đọc MPU6500 trực tiếp bằng thanh ghi raw I2C.
byte mpuI2CAddress = 0x68;

const byte MPU6500_REG_WHO_AM_I      = 0x75;
const byte MPU6500_REG_PWR_MGMT_1    = 0x6B;
const byte MPU6500_REG_CONFIG        = 0x1A;
const byte MPU6500_REG_GYRO_CONFIG   = 0x1B;
const byte MPU6500_REG_ACCEL_CONFIG  = 0x1C;
const byte MPU6500_REG_ACCEL_CONFIG2 = 0x1D;
const byte MPU6500_REG_ACCEL_XOUT_H  = 0x3B;

float accX = 0;
float accY = 0;
float accZ = 0;

float gyroX = 0;
float gyroY = 0;
float gyroZ = 0;

unsigned long lastMPUPrint = 0;

TwoWire I2C_MAX = TwoWire(1);

float fallAccMag = 0;
float fallPitch = 0;
float fallRoll = 0;

enum FallState {
  FALL_NORMAL,
  FALL_FREE,
  FALL_IMPACT,
  FALL_CHECK_STILL,
  FALL_CONFIRMED
};

FallState fallState = FALL_NORMAL;

unsigned long fallStateTime = 0;
unsigned long stillStartTime = 0;
unsigned long fallFreeStartTime = 0;
bool fallTiltSeen = false;

const float FREE_FALL_THRESHOLD = 0.65;
const float IMPACT_THRESHOLD = 2.05;
const float HARD_IMPACT_THRESHOLD = 2.75;
const float ANGLE_THRESHOLD = 50.0;
const float GYRO_STILL_THRESHOLD = 0.85;
const unsigned long FREE_FALL_MIN_TIME = 60;
const unsigned long FREE_FALL_MAX_TIME = 900;
const unsigned long IMPACT_TO_TILT_TIMEOUT = 1800;
const unsigned long STILL_TIME = 1800;

// =======================================================
// ALERT SYSTEM
// =======================================================

enum AlertType {
  ALERT_NONE,
  ALERT_FALL,
  ALERT_SOS
};

AlertType alertType = ALERT_NONE;

bool alertActive = false;
bool standbyMode = false;

// =======================================================
// STEP TRACKER / PEDOMETER - SMARTWATCH QUALITY
// =======================================================
// Lưu ý: đặt module MPU chắc vào cổ tay. Nếu cầm lắc trên tay, mọi thuật toán đều dễ sai.
int stepCount = 0;
int stepGoal = 10000;

// Hieu chinh theo nguoi deo de distance/kcal sat thuc te hon.
// Neu chua co ho so nguoi dung, 165 cm / 60 kg la moc trung binh de demo.
const float USER_HEIGHT_CM = 165.0f;
const float USER_WEIGHT_KG = 60.0f;
const float STEP_LENGTH_M = (USER_HEIGHT_CM * 0.415f) / 100.0f;
const float WALKING_KCAL_PER_KG_KM = 0.75f;  // kcal ~= can nang(kg) * km * 0.75

// Bộ lọc gia tốc cho thuật toán đếm bước
float stepGravity = 1.0f;             // nền gia tốc quanh 1g
float stepSignalFiltered = 0.0f;      // tín hiệu bước sau khi lọc cao/thấp
float lastStepSignal = 0.0f;
float stepPeakValue = 0.0f;
float stepValleyValue = 0.0f;
float stepNoiseAvg = 0.04f;
float stepDynamicThreshold = 0.12f;
float stepAmplitudeAvg = 0.18f;
float stepGyroBaseline = 0.0f;
float stepWristSignal = 0.0f;
bool stepAboveThreshold = false;

unsigned long lastStepTime = 0;             // lần cuối đã cộng bước thật
unsigned long lastStepCandidateTime = 0;    // lần cuối thấy đỉnh bước ứng viên
unsigned long stepPeakStartTime = 0;
unsigned long lastStepUpdateTime = 0;
unsigned long lastStepSampleTime = 0;
unsigned long activeWalkMs = 0;

byte stepWalkConfirmCount = 0;        // yêu cầu ít nhất 2 nhịp liên tiếp mới xác nhận đang đi
int stepCadenceSPM = 0;               // steps per minute để hiển thị/troubleshoot

unsigned long sedentaryStartTime = 0;
bool sedentaryWarning = false;

int hourlySteps[24];
int lastStepDayOfYear = -1;

// Thông số chống đếm nhầm. Có thể hiệu chỉnh sau khi test 100 bước thật.
const unsigned long STEP_SAMPLE_INTERVAL_MS = 20;    // 50Hz xử lý thuật toán
const unsigned long STEP_MIN_INTERVAL = 480;         // tranh 1 buoc bi dem thanh 3-4 buoc
const unsigned long STEP_MAX_INTERVAL = 1700;        // buoc cham vua phai
const unsigned long STEP_ACTIVE_WINDOW = 2500;
const unsigned long STEP_BURST_TIMEOUT = 2200;
const unsigned long STEP_PEAK_MIN_WIDTH_MS = 25;
const unsigned long STEP_PEAK_MAX_WIDTH_MS = 900;

const float STEP_THRESHOLD_MIN = 0.085f;   // can vung tay ro hon, bot dem lap
const float STEP_THRESHOLD_MAX = 0.32f;
const float STEP_MIN_AMPLITUDE = 0.130f;
const float STEP_MAX_SIGNAL = 1.60f;

// Cảnh báo ngồi lâu. Để test nhanh có thể đổi 60 phút thành 1-2 phút.
const unsigned long SEDENTARY_LIMIT_MS = 60UL * 60UL * 1000UL;

// =======================================================
// GRAPH
// =======================================================

const int GRAPH_X = 10;
const int GRAPH_Y = 168;
const int GRAPH_W = 220;
const int GRAPH_H = 90;

const int GRAPH_DATA_SIZE = GRAPH_W;

uint32_t graphData[GRAPH_DATA_SIZE];

// Lưu 60 giá trị BPM gần nhất để hiện MAX/MIN giống giao diện smartwatch.
const int HR_TREND_SIZE = 60;
int hrTrendData[HR_TREND_SIZE];
byte hrTrendCount = 0;
int hrTrendMax = 0;
int hrTrendMin = 0;

const uint32_t GRAPH_MIN = 20000;
const uint32_t GRAPH_MAX = 120000;

unsigned long lastScreenUpdate = 0;
const unsigned long SCREEN_UPDATE_INTERVAL = 500;

// =======================================================
// BUTTON DEBOUNCE
// =======================================================

struct Button {
  int pin;
  bool lastReading;
  bool stableState;
  unsigned long lastDebounceTime;
  unsigned long pressStartTime;
  bool shortPressEvent;
  bool longPressEvent;
  bool longFired;
};

Button buttonA;
Button buttonB;

const unsigned long DEBOUNCE_DELAY = 40;
const unsigned long LONG_PRESS_TIME = 2000;   // nhấn giữ 2s để SOS

// =======================================================
// FUNCTION PROTOTYPES - giup Arduino IDE khong loi thu tu tab
// =======================================================
bool checkI2CDevice(TwoWire &bus, byte address);
void scanI2C(TwoWire &bus, const char *busName);
void initButton(Button &btn, int pin);
void updateButton(Button &btn);
void triggerSOSFromButton(const char *buttonName);
void wakeScreenForButtonAction();
void goToNextScreen();
void goToPreviousScreen();
void resetHealthBuffers();
void resetHealthAcquisitionOnly();
void clearAlert();
void showMessage(String line1, String line2);
void showMessage(String line1);
void showError(String title, String line2);
void handleButtons();
void updateBuzzer();
void setupBatteryMonitor();
void updateBatteryMonitor();
bool mpuWrite8(byte reg, byte value);
bool mpuReadBytes(byte reg, byte count, byte *data);
byte mpuRead8(byte reg);
int16_t combine16(byte highByte, byte lowByte);
bool readMPU6500();
void updateFallDetection();
String formatNumberWithComma(long value);
float getStepDistanceKm();
int getStepCalories();
int getStepGoalPercent();
int getCurrentHourForSteps();
void resetStepDataForNewDay();
void resetStepsDailyIfNeeded();
void addOneStep();
void registerStepCandidate(unsigned long now);
void updateStepTracker();
void pushGraphData(uint32_t value);
void pushHeartRateTrend(int bpm);
int medianSmall(int *values, byte count);
bool isHealthResultReady();
bool isHeartRateAlertActive();
String heartRateAlertLevel();
void clearExpiredHealthDisplay();
void addHRValue(int bpm);
void addSpO2Value(int value);
void sortU32Small(uint32_t *arr, int n);
SignalStats calculateSignalStats();
bool isSignalGood(const SignalStats &s);
void applyLedLevel();
void autoTuneLed(uint32_t irValue, uint32_t redValue);
int calculateBPMFromExtrema(int32_t *ac, int threshold, bool detectPeak);
int calculateBPMByAutocorrelation(int32_t *ac);
int calculateBPMBySpectrum(int32_t *ac);
int estimateLiveSpO2FromPartialBuffer();
void updateLiveSpO2Preview();
int calculateHeartRateFromIRBuffer();
void processCompletedHealthWindow();
bool wakeMAX30102();
bool resetMAX30102(const char *reason);
void updateMAX30102Watchdog();
void processHealthSensor();
void connectWiFi();
void syncTimeFromNTP();
void updateClock();
String weatherCodeToText(int code);
String getJsonObject(const String &payload, const char *objectName);
float getJsonFloatValue(const String &json, const char *key, float fallback);
void setWeatherOffline(String reason);
void updateWeatherNow();
void updateWeatherIfNeeded();
String firebaseEscape(String value);
String buildFirebasePayload();
bool sendTelemetryToFirebase();
void markFirebaseHealthWindowReady();
void markFirebaseHealthCleared();
void forceFirebaseSendOnNextChange();
void updateFirebaseIfNeeded();
void drawBatteryIcon(int x, int y, int percent);
void drawArcSegments(int16_t x, int16_t y, int16_t radius, int startDeg, int endDeg, uint16_t color);
void drawWifiIcon(int16_t x, int16_t y, float scale, bool connected);
void drawLinkIcon(int x, int y);
void drawWatchCaseFrame();
void drawWeatherIcon(int16_t x, int16_t y, float scale);
void drawHeartIcon(int x, int y, uint16_t color);
void drawThermoIcon(int x, int y, uint16_t color);
void drawECGLine(int x, int y, uint16_t color);
void drawCenteredDefaultText(String text, int boxX, int boxY, int boxW, int boxH, uint8_t textSize, uint16_t color);
void drawStatusCard(int x, int y, int w, int h);
void drawSpO2Icon(int x, int y, uint16_t color);
void drawAlertScreen();
void drawWeatherValues();
void drawHomeWatchFace();
void drawHealthSoftGlowCard(int x, int y, int w, int h, uint16_t bg, uint16_t border);
void drawTinyWifiEqualBox(int x, int y, bool connected);
void drawTinyBatteryEqualBox(int x, int y, int percent);
void drawHealthTopBar();
void drawHealthStatusPill(int x, int y, const char *text, uint16_t color);
void drawHeartCircleIcon(int cx, int cy);
void drawSpO2CircleIcon(int cx, int cy);
void drawHealthGraphGrid();
void drawHealthGraphAxes(bool drawLabels);
void drawStaticHealthScreen();
void drawHealthDynamicValues();
int healthGraphMapYDynamic(uint32_t value, uint32_t minV, uint32_t maxV, int gy, int gh);
void drawPremiumHealthGraph();
void drawHealthScreen();
void drawThickArc(int16_t cx, int16_t cy, int16_t radius, int startDeg, int endDeg, int thick, uint16_t color);
void drawStepFootIcon(int cx, int cy, uint16_t color);
void drawLocationIcon(int cx, int cy, uint16_t color);
void drawFlameIcon(int cx, int cy, uint16_t color);
void drawClockIconSmall(int cx, int cy, uint16_t color);
void drawTargetIcon(int cx, int cy, uint16_t color);
void drawSittingIcon(int cx, int cy, uint16_t color);
void drawWalkingIcon(int cx, int cy, uint16_t color);
void drawStepMetricCard(int x, int y, int w, int h, const char *label, uint16_t accent, byte iconType);
void drawStepProgressRing();
void drawStaticStepScreen();
void drawStepMainValues();
void drawMetricValueText(int x, int y, int w, String value, String unit, uint16_t color);
void drawStepMetricValues();
void drawStepScreen();
void drawMainScreen();
void setupMAX30102();
void setupMPU6500();

// ==============================================================
// SETUP
// file chính: include, biến global, setup(), loop()
// ==============================================================
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
void loop() {
  handleButtons(); 
  updateBatteryMonitor();
  updateClock();
  updateWeatherIfNeeded();

  updateFallDetection();
  updateStepTracker();
  resetStepsDailyIfNeeded();

  // Doc MAX30102 truoc, sau do watchdog moi kiem tra.
  // Neu WiFi/Firebase lam loop cham, FIFO co mau se duoc doc truoc khi watchdog quyet dinh reset.
  processHealthSensor();
  updateMAX30102Watchdog();

  // Gửi dữ liệu mới nhất lên Firebase Realtime Database
  updateFirebaseIfNeeded();

  updateBuzzer();

  if (millis() - lastScreenUpdate >= SCREEN_UPDATE_INTERVAL) {
    lastScreenUpdate = millis();
    drawMainScreen();
  }

  delay(10);
}

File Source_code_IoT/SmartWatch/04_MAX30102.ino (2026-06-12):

// ==============================================================
// 04_MAX30102.ino
// đo nhịp tim, SpO2, watchdog/reset MAX30102, setup MAX30102
// ==============================================================

void resetHealthBuffers() {
  bufferIndex = 0;

  for (int i = 0; i < BUFFER_LENGTH; i++) {
    irBuffer[i] = 0;
    redBuffer[i] = 0;
    sampleTimeBuffer[i] = 0;
  }

  for (int i = 0; i < GRAPH_DATA_SIZE; i++) {
    graphData[i] = GRAPH_MIN;
  }

  for (int i = 0; i < HR_TREND_SIZE; i++) {
    hrTrendData[i] = 0;
  }
  hrTrendCount = 0;
  hrTrendMax = 0;
  hrTrendMin = 0;

  heartRate = 0;
  spo2 = 0;
  validHeartRate = 0;
  validSPO2 = 0;
  displayHeartRate = 0;
  displaySpO2 = 0;

  hrHistoryCount = 0;
  hrHistoryIndex = 0;
  spo2HistoryCount = 0;
  spo2HistoryIndex = 0;

  for (int i = 0; i < HR_SMOOTH_SIZE; i++) hrHistory[i] = 0;
  for (int i = 0; i < SPO2_SMOOTH_SIZE; i++) spo2History[i] = 0;

  hrPendingValue = 0;
  hrPendingCount = 0;
  lastHRAuto = 0;
  lastHRExtrema = 0;
  lastHRCandidate = 0;
  lastHRWindowMedian = 0;
  lastHRWindowValidCount = 0;
  lastHRActualFs = 0;
  lastHRDurationMs = 0;
  lastHRAcRange = 0;
  lastHRThreshold = 0;
  lastHRPeakCount = 0;
  lastHRValleyCount = 0;
  lastHRAutoScore = 0;
  lastHRSpectrum = 0;
  lastHRSpectrumScore = 0;
  lastHRSpectrumSeparation = 0;
  lastLiveSpO2EstimateMs = 0;
  lastLiveSpO2Estimate = 0;
  lastLiveSpO2Quality = 0;
  lastRawRatioX100 = 0;
  lastAdjustedRatioX100 = 0;
  lastHRQuality = 0;
  lastHRRejectReason = 0;
  lastWristMotionScore = 0;
  wristBadSampleCount = 0;
  wristDroppedSamples = 0;
  lastGoodIRValue = 0;
  lastGoodREDValue = 0;
  lastValidHeartRateMs = 0;
  lastValidSpO2Ms = 0;
  lastFingerLostMs = 0;

  signalOK = false;
}


void pushGraphData(uint32_t value) {
  for (int i = 0; i < GRAPH_DATA_SIZE - 1; i++) {
    graphData[i] = graphData[i + 1];
  }

  graphData[GRAPH_DATA_SIZE - 1] = value;
}


void pushHeartRateTrend(int bpm) {
  if (bpm < 40 || bpm > 160) return;

  for (int i = 0; i < HR_TREND_SIZE - 1; i++) {
    hrTrendData[i] = hrTrendData[i + 1];
  }
  hrTrendData[HR_TREND_SIZE - 1] = bpm;

  if (hrTrendCount < HR_TREND_SIZE) hrTrendCount++;

  hrTrendMax = 0;
  hrTrendMin = 999;

  int start = HR_TREND_SIZE - hrTrendCount;
  for (int i = start; i < HR_TREND_SIZE; i++) {
    if (hrTrendData[i] <= 0) continue;
    if (hrTrendData[i] > hrTrendMax) hrTrendMax = hrTrendData[i];
    if (hrTrendData[i] < hrTrendMin) hrTrendMin = hrTrendData[i];
  }

  if (hrTrendMin == 999) hrTrendMin = 0;
}


int medianSmall(int *values, byte count) {
  if (count == 0) return 0;

  int tmp[8];
  if (count > 8) count = 8;

  for (byte i = 0; i < count; i++) tmp[i] = values[i];

  for (byte i = 0; i < count - 1; i++) {
    for (byte j = i + 1; j < count; j++) {
      if (tmp[j] < tmp[i]) {
        int t = tmp[i];
        tmp[i] = tmp[j];
        tmp[j] = t;
      }
    }
  }

  return tmp[count / 2];
}


int medianIntInPlace(int *values, int count) {
  if (count <= 0) return 0;

  for (int i = 0; i < count - 1; i++) {
    for (int j = i + 1; j < count; j++) {
      if (values[j] < values[i]) {
        int t = values[i];
        values[i] = values[j];
        values[j] = t;
      }
    }
  }

  if (count % 2 == 1) return values[count / 2];
  return (values[count / 2 - 1] + values[count / 2]) / 2;
}


bool isNormalStableHR(int bpm) {
  return bpm >= HR_STABLE_LOW_BPM && bpm <= HR_STABLE_HIGH_BPM;
}


bool isStableSpO2Value(int value) {
  return value >= SPO2_STABLE_LOW && value <= SPO2_STABLE_HIGH;
}


int limitStepToward(int currentValue, int newValue, int maxStep) {
  if (currentValue <= 0) return newValue;
  int delta = newValue - currentValue;
  if (delta > maxStep) return currentValue + maxStep;
  if (delta < -maxStep) return currentValue - maxStep;
  return newValue;
}

bool isHealthResultReady() {
  return fingerDetected &&
         validHeartRate && displayHeartRate >= HR_ALGO_MIN_BPM && displayHeartRate <= HR_ALGO_MAX_BPM &&
         validSPO2 && displaySpO2 >= 90 && displaySpO2 <= 100;
}


bool isHeartRateAlertActive() {
  return isHealthResultReady() &&
         (displayHeartRate > HR_ALERT_HIGH_BPM || displayHeartRate < HR_ALERT_LOW_BPM);
}


String heartRateAlertLevel() {
  if (!isHeartRateAlertActive()) return "normal";
  if (displayHeartRate > HR_ALERT_HIGH_BPM) return "high";
  return "low";
}


void clearExpiredHealthDisplay() {
  if (lastFingerLostMs == 0) return;
  if (millis() - lastFingerLostMs <= KEEP_LAST_HEALTH_VALUE_MS) return;

  fingerDetected = false;
  bufferIndex = 0;
  validHeartRate = 0;
  validSPO2 = 0;
  heartRate = 0;
  spo2 = 0;
  displayHeartRate = 0;
  displaySpO2 = 0;
  hrHistoryCount = 0;
  hrHistoryIndex = 0;
  spo2HistoryCount = 0;
  spo2HistoryIndex = 0;
  hrPendingValue = 0;
  hrPendingCount = 0;
  lastLiveSpO2Estimate = 0;
  lastLiveSpO2Quality = 0;
  signalOK = false;
  lastFingerLostMs = 0;
  markFirebaseHealthCleared();
  forceFirebaseSendOnNextChange();
  Serial.println("Da bo tay khoi cam bien qua vai giay -> an BPM/SpO2 khoi man hinh.");
}
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

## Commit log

2026-05-16 Add file 3D
    [Bottom.stl, Top.stl, watch_case_3d.scad]
2026-06-06 cập nhật web server theo dõi sức khỏe
2026-06-10 update giao diện web
2026-06-10 update giao diện web theo dõi sức khỏe
2026-06-10 update giao diện web theo dỗi sức khỏe
